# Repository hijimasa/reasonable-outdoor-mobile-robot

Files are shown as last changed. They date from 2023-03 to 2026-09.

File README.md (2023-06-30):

# 廉価版屋外向け移動ロボットプラットフォーム

# 注意事項
## 本プロジェクトのロボットに古いファームウェアであるM1502D_211のモーターを使用すると、速度フィードバックモードを有効にすると制御が発散するのか激しく振動する現象が確認されています。現在はオープンループモードを用いてArduino内でPID制御を入れることによって改善を図ってるので、ロボットに合わせて適宜パラメータチューニングが必要です。
   
# 概要
このリポジトリは、つくばチャレンジや中之島チャレンジで個人参加しやすい廉価な屋外向け移動ロボットプラットフォームを実現するために立ち上げたものです。
できるだけ廉価になるように設計してみたのですが、材料費は20万円程度となってしまったので、個人が手軽に始められるかどうかはちょっと怪しいです。
私個人が実験的に作成したものなので、質問やissueなどにはできる限り回答しますが、利活用は各々の自己責任のもとで行ってください。
本リポジトリが屋外向け移動ロボット開発の一助となれば幸いです。

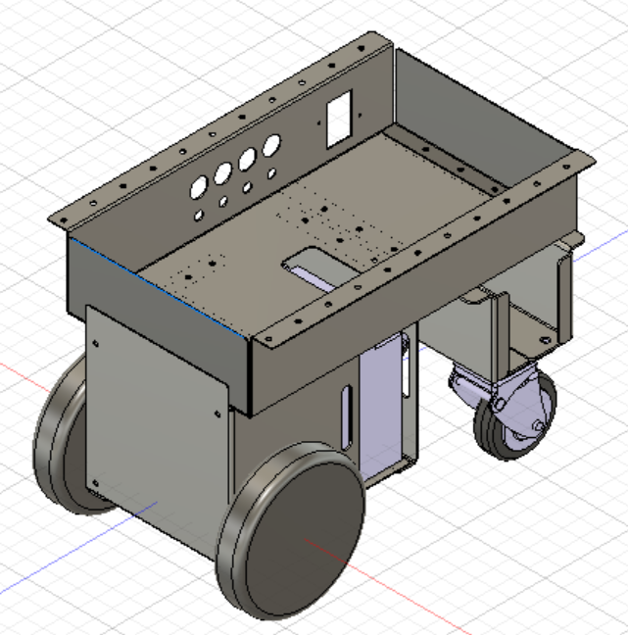
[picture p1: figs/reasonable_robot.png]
ロボット外観


# 特徴

- Direct Drive Tech社のタイヤ付きモータを採用

  タイヤの組付けなどの作業を省略した上で、部品数の低減に貢献しています。

- 24V20Ah相当のバッテリー搭載

  12V20Ahの鉛蓄電池を2つ直列に搭載しました。常時フル稼働でモータを駆動させるわけではないのであれば、屋外実験に十分な容量があると考えています。

- 自作のモータコントローラにより非常停止やブレーキ解除を実現

  今回採用したモータには非常停止やブレーキの解除機能がなく、作業性や安全面で問題があったので、制御PCとは独立したArduinoで機能を実現しました。
  何らかの規格に則っているわけではないので、安全性などについては今後の課題となっています。

# リポジトリの構成

- CAD

  様々な3DCADツールで利用しやすいSTEPファイルとROSでシミュレーションする際に利用できるSTLファイルを用意しています。
  
- schematics

  プラットフォームの回路図です。基本的にモータに電源とArduinoをつなげるだけです。

- BoM

  ロボット製作に必要となった部品表とかかった金額のメモです。参考までに。
  
- tools
  
  本リポジトリのロボットを活用するためのツールとして、モータのID変更やコントローラに関するArduinoプロジェクトなどを格納しています。
  
# 参照

- ROSパッケージ

  [reasonable_outdoor_mobile_robot_ros_controller](https://github.com/hijimasa/reasonable_outdoor_mobile_robot_ros_controller)
  
- ROS2パッケージ

  [reasonable_outdoor_mobile_robot_ros2_controller](https://github.com/hijimasa/reasonable_outdoor_mobile_robot_ros2_controller)

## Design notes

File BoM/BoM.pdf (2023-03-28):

## 廉価版屋外向け移動ロボットプラットフォーム 部品表

## 合計金額

品名 | 個数 | 参考単価 | 参考金額
DDT M1502D_211 タイヤ付きダイレクトドライブモーター | 2 | ￥41,536 | ￥83,072
Arduino Uno R3 | 1 | ￥3,960 | ￥3,960
SeeedStudio CAN-BUSシールド V2 | 1 | ￥4,070 | ￥4,070
LONG WP20-12 鉛蓄電池 | 2 | ￥7,590 | ￥15,180
シシク SAJ-100W キャスター | 2 | ￥6,990 | ￥13,980
パトライト TC60C06 端子台 | 2 | ￥1,490 | ￥2,980
パトライト JTJ602B ショートバー(10個セット) | 1 | ￥2,290 | ￥2,290
エーモン工業 2826 簡単接続分岐コネクター | 1 | ￥399 | ￥399
三菱電機 NF50-FA ブレーカー | 1 | ￥4,990 | ￥4,990
JAPPY IV 8sq 赤 JP ビニル絶縁電線(10m) | 1 | ￥2,290 | ￥2,290
JAPPY IV 8sq 黒 JP ビニル絶縁電線(10m) | 1 | ￥2,290 | ￥2,290
鍋屋バイテック SSHS-M6-6 ネジ（10本セット） | 3 | ￥1,390 | ￥4,170
モノタロウ MR8-6B(t=1.2) （100個セット） | 1 | ￥1,390 | ￥1,390
栃木屋 TM-MG-6 グロメット | 4 | ￥53 | ￥212
モノタロウ 73367954 防水トグルスイッチ | 1 | ￥1,890 | ￥1,890
ANDERSON POWER PRODUCTS 6331G3 バッテリコネクタ | 3 | ￥689 | ￥2,067
電菱 GC120A24 バッテリー充電器 | 1 | ￥11,900 | ￥11,900
【板金】MotorPlateBottom | 1 | ￥2,500 | ￥2,500
【板金】BatteryPlateBottom | 1 | ￥2,500 | ￥2,500
【板金】CasterPlate | 2 | ￥4,500 | ￥9,000
【板金】BatteryPlate | 2 | ￥4,500 | ￥9,000
【板金】MotorPlateLeft | 1 | ￥5,000 | ￥5,000
【板金】MotorPlateRight | 1 | ￥5,000 | ￥5,000
【板金】Futa | 1 | ￥3,000 | ￥3,000
【板金】BasePlate | 1 | ￥9,000 | ￥9,000
【板金】FrontPlate | 1 | ￥2,500 | ￥2,500
【板金】RearPlate | 1 | ￥2,500 | ￥2,500

￥207,130

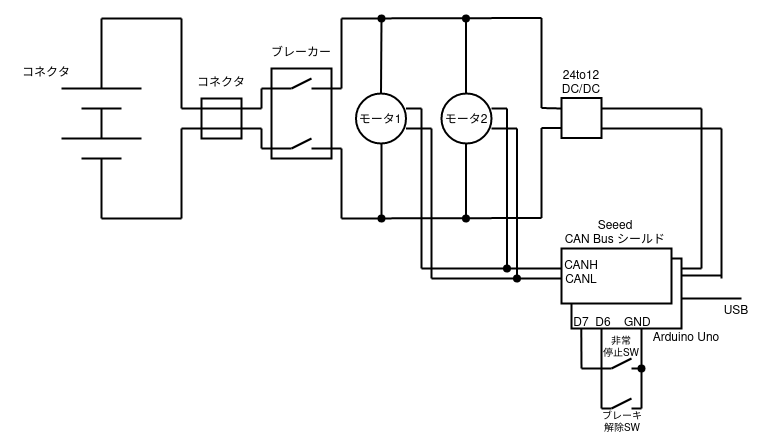
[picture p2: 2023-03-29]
schematics/schematics.png

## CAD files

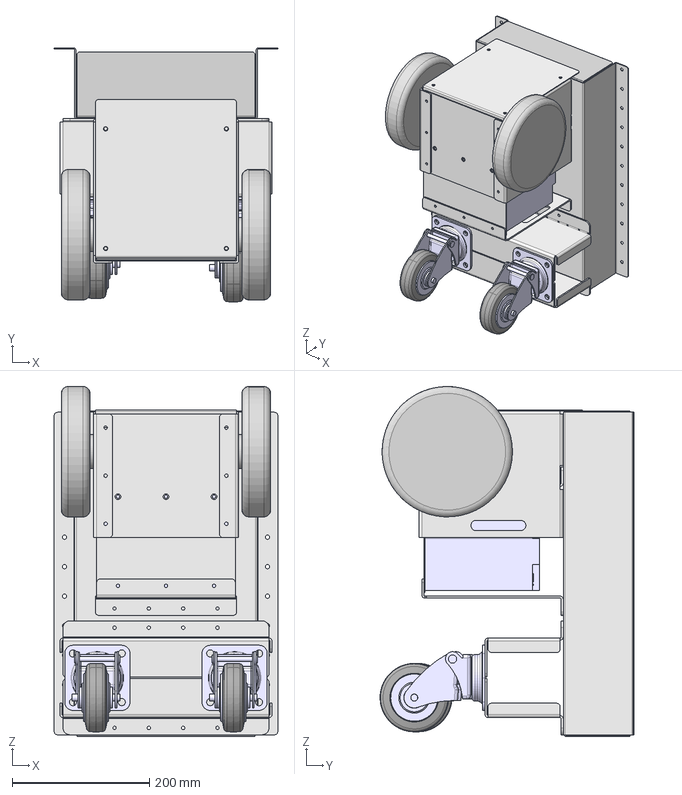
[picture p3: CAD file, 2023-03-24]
CAD/STEP/ReasonableOutdoorMobileRobot v14.step
326.0 x 369.9 x 510.0 mm
DDT_M1502D_211 x 2
SAJ-100W_TURN x 2
battery-22ah x 2
ReasonableOutdoorMoblieRobot-CasterPlate x 2
ReasonableOutdoorMoblieRobot-BatteryPlate x 2
ReasonableOutdoorMoblieRobot-BasePlate
ReasonableOutdoorMobileRobot-MotorPlateRight
ReasonableOutdoorRobot-Futa
SAJ-100W_TOP x 2
ReasonableOutdoorMobileRobot-BatteryPlateBottom
ReasonableOutdoorMobileRobot-MotorPlateBottom
ReasonableOutdoorMobileRobot-MotorPlateLeft
ReasonableOutdoorMobileRobot-RearPlate
ReasonableOutdoorMobileRobot-FrontPlate
SAJ-100W_TIRE x 2

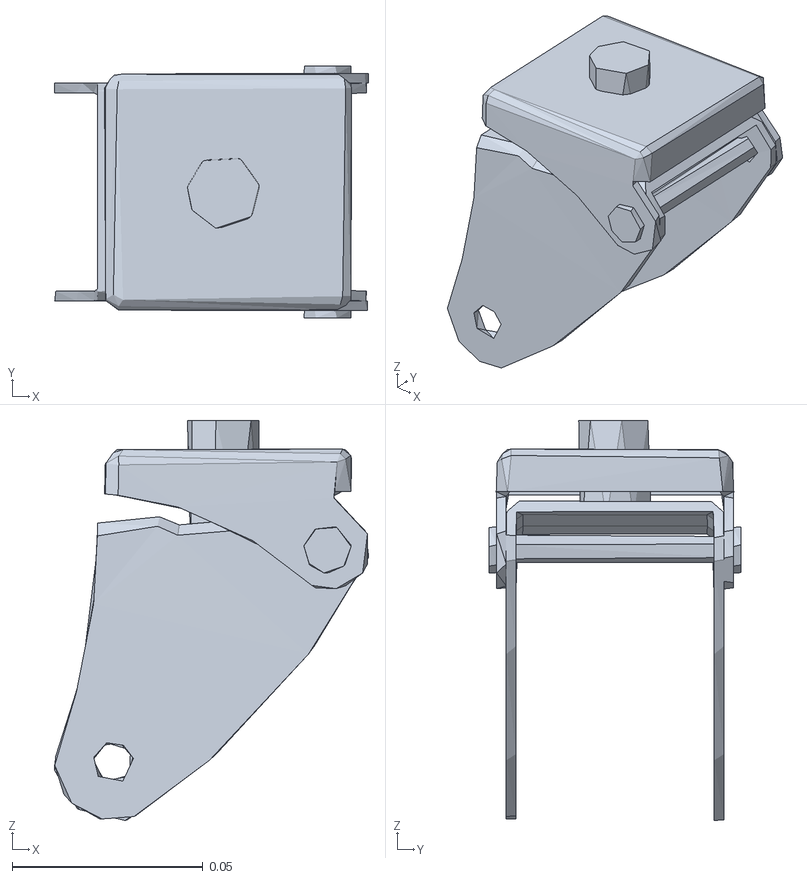
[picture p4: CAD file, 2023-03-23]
CAD/STL/SAJ-100W_TURN_light.stl
0.0823 x 0.066 x 0.105

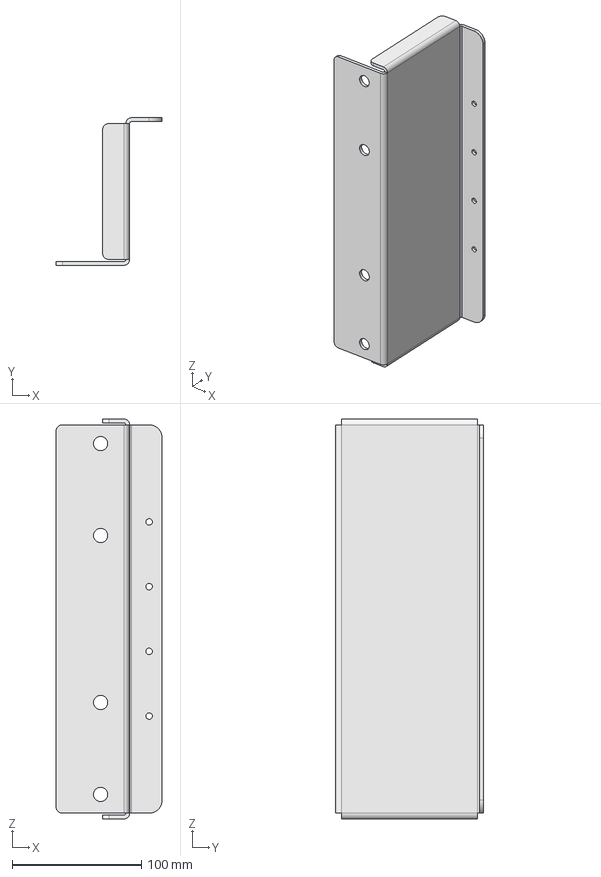
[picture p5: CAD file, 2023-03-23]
CAD/STEP/ReasonableOutdoorMoblieRobot-CasterPlate v20.step
82.0 x 114.0 x 309.0 mm

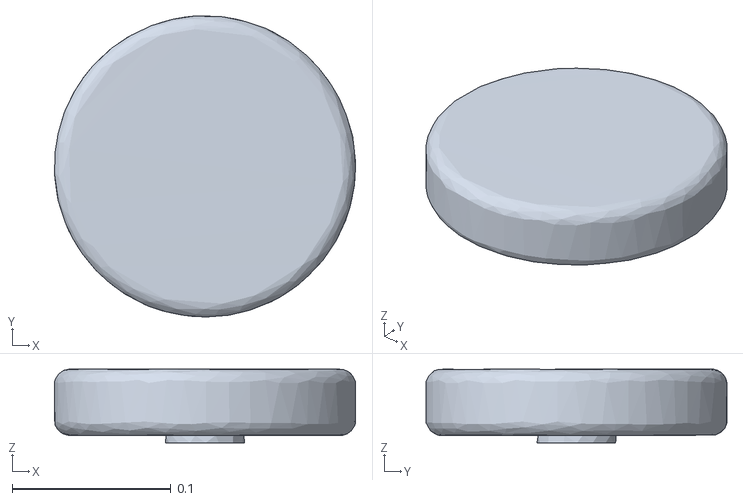
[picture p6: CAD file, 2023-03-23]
CAD/STL/DDT_M1502D_211_light.stl
0.19 x 0.19 x 0.0465

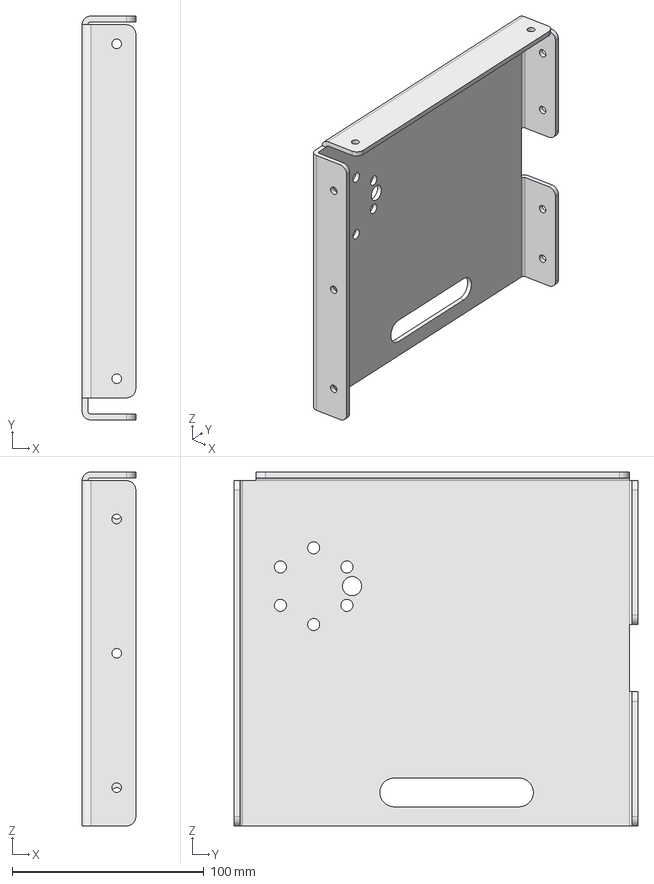
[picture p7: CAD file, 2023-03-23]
CAD/STEP/ReasonableOutdoorMobileRobot-MotorPlateRight v22.step
28.0 x 210.5 x 184.5 mm

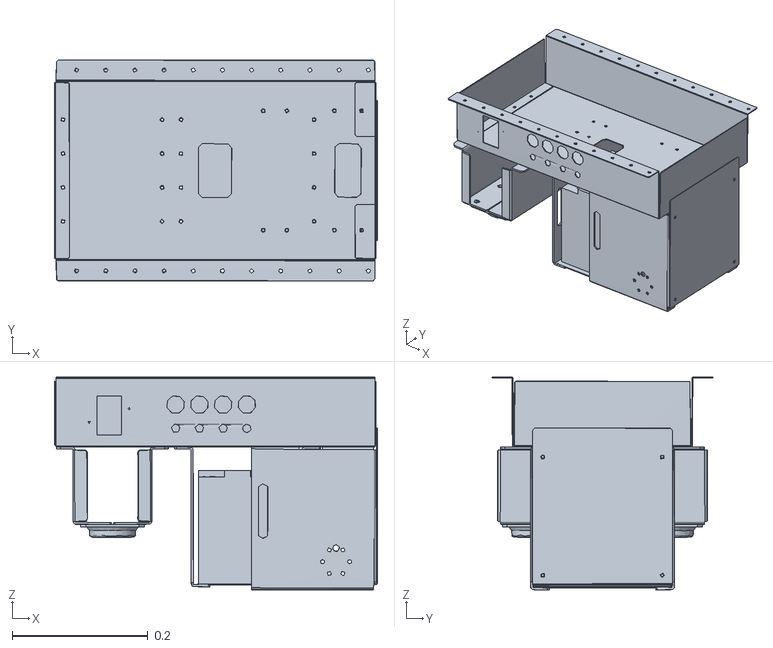
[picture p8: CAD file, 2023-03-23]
CAD/STL/ReasonableOutdoorMobileRobot-BaseUnit_light.stl
0.476 x 0.325 x 0.314

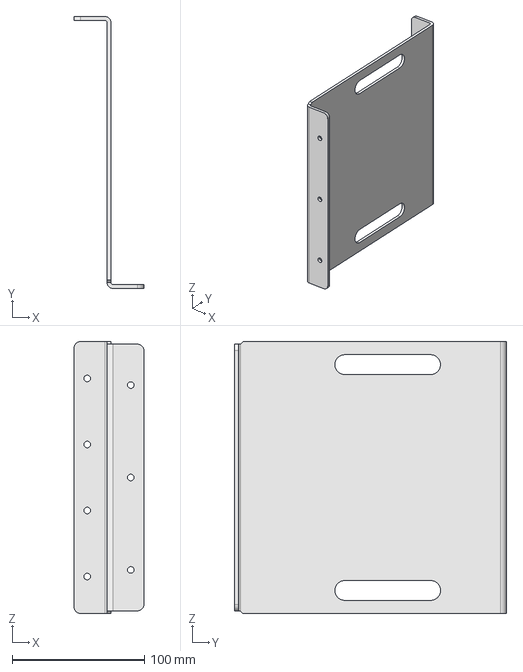
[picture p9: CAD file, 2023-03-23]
CAD/STEP/ReasonableOutdoorMoblieRobot-BatteryPlate v11.step
53.0 x 206.0 x 206.0 mm

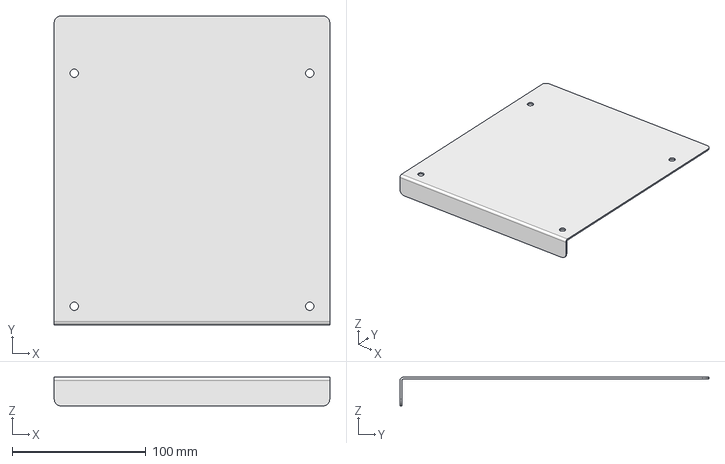
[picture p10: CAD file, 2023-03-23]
CAD/STEP/ReasonableOutdoorRobot-Futa v9.step
206.0 x 231.0 x 21.5 mm

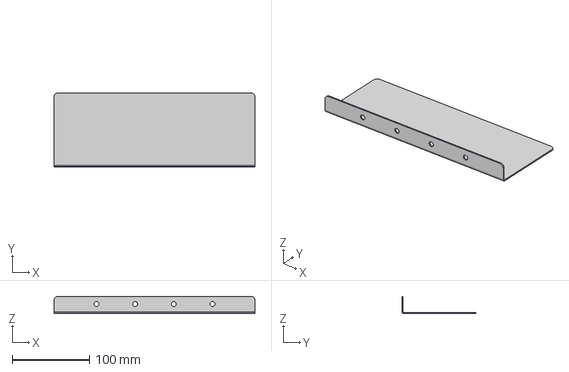
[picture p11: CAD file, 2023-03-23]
CAD/STEP/ReasonableOutdoorMobileRobot-RearPlate v4.step
260.0 x 96.0 x 22.5 mm

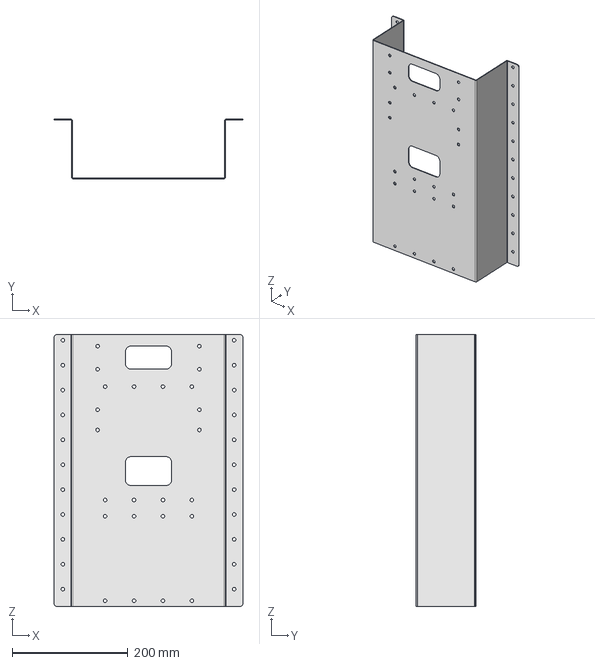
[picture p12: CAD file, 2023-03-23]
CAD/STEP/ReasonableOutdoorMoblieRobot-BasePlate v36.step
326.0 x 103.0 x 470.0 mm

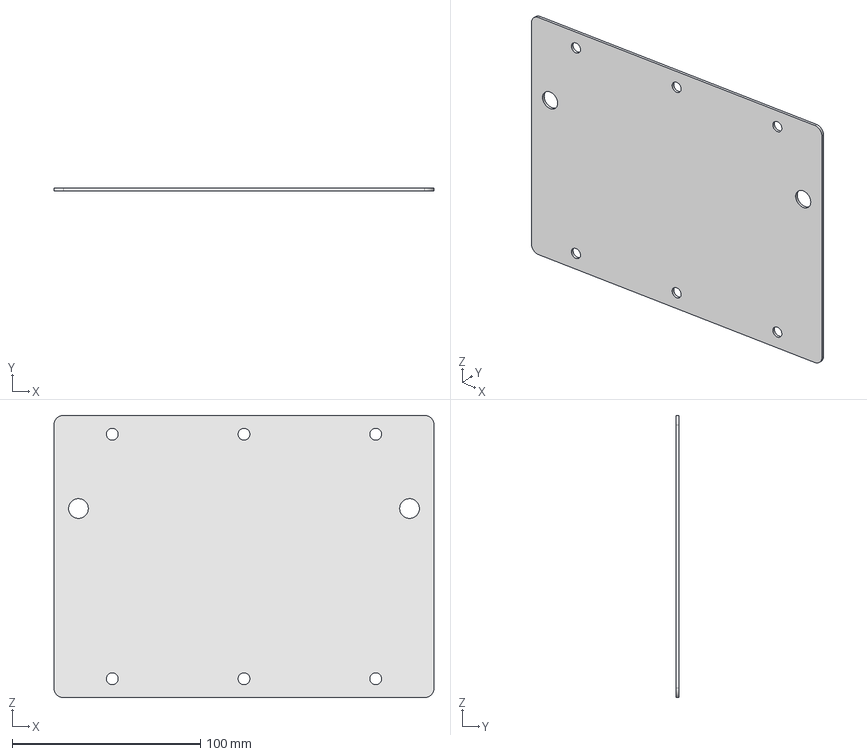
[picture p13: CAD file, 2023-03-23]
CAD/STEP/ReasonableOutdoorMobileRobot-BatteryPlateBottom v5.step
202.0 x 1.50 x 150.0 mm

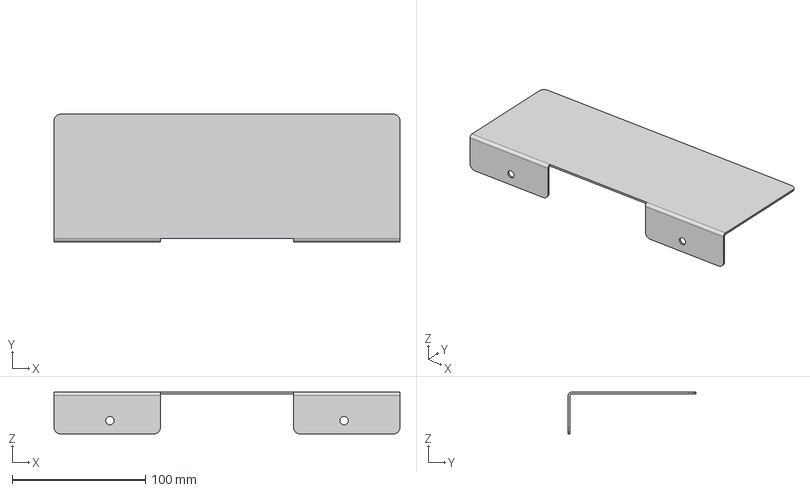
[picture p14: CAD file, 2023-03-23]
CAD/STEP/ReasonableOutdoorMobileRobot-FrontPlate v5.step
260.0 x 96.0 x 31.5 mm

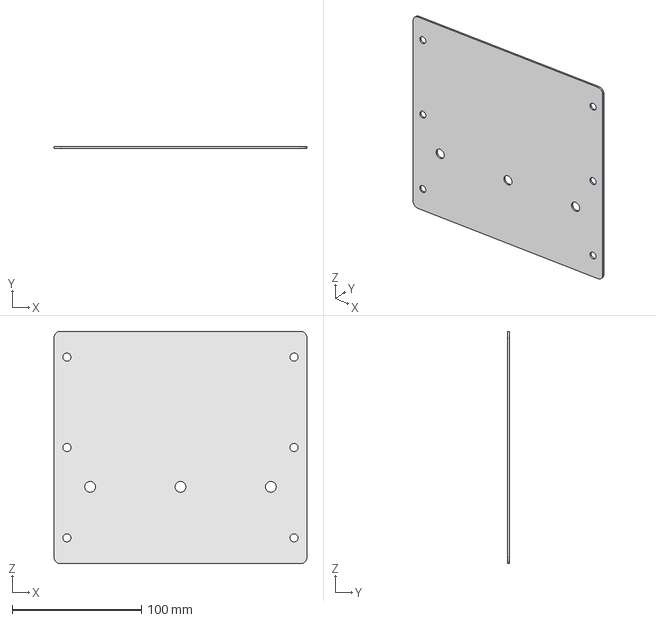
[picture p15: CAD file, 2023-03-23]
CAD/STEP/ReasonableOutdoorMobileRobot-MotorPlateBottom v3.step
196.0 x 1.50 x 180.0 mm

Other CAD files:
CAD/STEP/ReasonableOutdoorMobileRobot-MotorPlateLeft v4.step
CAD/STEP/CheepOutdoorMobileRobot v14.step

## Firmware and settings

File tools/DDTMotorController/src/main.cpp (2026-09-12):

#include <Arduino.h>
#include <SPI.h>
#include "mcp2515_can.h"

const int SPI_CS_PIN = 9;
mcp2515_can CAN(SPI_CS_PIN);

const int EMERGENCY_PIN = 7;
const int FREE_ROTATION_PIN = 6;

const int motor_total_num = 2;

// Which way a positive duty turns each motor, relative to the direction that
// motor reports as positive velocity. Measured on the bench with the wheels
// off the ground (tools/DDTMotorSignTest, 2026-09-12): ramping motor 0 to
// +4000 made it report -19 rpm with its angle falling, and -4000 made it
// report +20 rpm with the angle rising, while motor 1 reported +27 and -27 the
// obvious way round. So motor 0 is wired the other way about.
//
// The PID compares a target with that reported velocity, so without this the
// loop on motor 0 is positive feedback: a -1 rpm target drove the duty down,
// which drove the reported velocity up, which made the error more negative
// still, and the duty reached the rail inside four seconds. Commanded -1.3
// rpm, the wheel ran at +88 and the robot turned at 3.5 rad/s against a
// 0.1 rad/s request.
//
// This belongs on the duty and not on the feedback: the feedback is what the
// host integrates into odometry, and that was checked against a hand-turned
// wheel on 2026-09-06 and is right as it stands.
const int motor_duty_sign[8] = {-1, 1, 1, 1, 1, 1, 1, 1};
const int motor_decelation = 2000;
int motor_velocities[8]         = {0, 0, 0, 0, 0, 0, 0, 0};
int current_motor_velocities[8] = {0, 0, 0, 0, 0, 0, 0, 0};
int current_motor_currents[8]   = {0, 0, 0, 0, 0, 0, 0, 0};
int current_motor_angles[8]     = {0, 0, 0, 0, 0, 0, 0, 0};
int current_command[8]          = {0, 0, 0, 0, 0, 0, 0, 0};
int diff_vel[8][4]             = {{0}};
int diff_vel_index              = 0;
int k_p                         =  80;
int k_d                         =  10;
int k_i                         =  40;
bool is_drive_mode = false;

// Host link. One 6-byte frame per command: 0x55, two int16 rpm big-endian,
// checksum = sum of the first 5 bytes. The reply is 0x55, three int16 per
// motor (angle, rpm, current), checksum -- 14 bytes for two motors.
const int command_len = motor_total_num * 2 + 2;
byte command[command_len];
int command_len_received = 0;
// Stop the motors when the host goes quiet. Measured in time, not loop
// iterations, so it does not depend on how long a loop takes.
const unsigned long command_timeout_ms = 500;
unsigned long last_command_ms = 0;

// 500 kbaud, not 9600. A command is 6 bytes and a reply 14, which at 9600 is
// 20.8 ms on the wire every control cycle -- comparable to everything else the
// loop does. 500000 divides 16 MHz exactly (UBRR 3 with U2X, 0.00% error) and
// is a standard Linux baud constant, so both ends land on it without a
// mismatch; 115200 would be +2.12% on this AVR, inside 8N1 tolerance but with
// the least margin of the candidates and no benefit here. The host must be
// rebuilt with B500000 at the same time or the link goes silent.
const unsigned long HOST_BAUD = 500000;

// The PID below is an incremental form with no dt: k_i * error is added once
// per iteration, so the integral gain is proportional to the loop rate and the
// period is part of the tuning. It used to be three delay(10) calls -- two
// waiting for CAN status replies and one at the end -- so 30 ms whenever the
// motors answered promptly. Keeping the same 30 ms, held deliberately rather
// than falling out of where the sleeps landed, leaves the motor loop tuned as
// it was.
//
// It also has to stay paced: at 500 kbps a CAN frame is about 0.26 ms and this
// loop sends six of them, so running free would put the bus near saturation.
const unsigned long LOOP_PERIOD_MS = 30;

// The motors answer a status request in well under a millisecond. delay(10)
// spent ten of them doing nothing, twice a loop, and tied the loop period to
// where that tick happened to fall. checkReceive() is an SPI read, so this
// polls at SPI speed rather than spinning on nothing.
const unsigned long CAN_REPLY_TIMEOUT_US = 20000;

static bool waitForCanFrame(unsigned long timeout_us)
{
  const unsigned long start = micros();
  while (CAN_MSGAVAIL != CAN.checkReceive())
  {
    if (micros() - start > timeout_us)
    {
      return false;
    }
  }
  return true;
}

void setup() {
  unsigned char read_len;
  unsigned char read_buf[16];

  pinMode(EMERGENCY_PIN, INPUT_PULLUP);
  pinMode(FREE_ROTATION_PIN, INPUT_PULLUP);

  Serial.begin(HOST_BAUD);

  while (CAN_OK != CAN.begin(CAN_500KBPS)) {             // init can bus : baudrate = 500k
    delay(100);
  }

  unsigned char registor_stmp[8] = {0x00, 0x00, 0, 0, 0, 0, 0, 0};
  CAN.sendMsgBuf(0x109, 0, 8, registor_stmp);
  delay(10);

  unsigned char feedback_stmp[8] = {0x80, 0x80, 0, 0, 0, 0, 0, 0};
  CAN.sendMsgBuf(0x106, 0, 8, feedback_stmp);
  delay(10);

  // flush can data
  while (1)
  {
    int timeout_count = 0;
    while (CAN_MSGAVAIL != CAN.checkReceive())
    {
      delay(10);
      timeout_count++;
      if (timeout_count > 100)
      {
        break;
      }
    }
    if (timeout_count > 100)
    {
      break;
    }

    CAN.readMsgBuf(&read_len, read_buf);
  }
}

// Answer whatever the host has sent. Called from loop() and again while the
// loop waits out its period, so a command is replied to within microseconds
// of arriving instead of whenever the loop next comes round to it. The reply
// used to be assembled once a pass, behind the CAN status polling, so its
// latency was anywhere from nothing to a full loop depending on when the
// command landed -- and that spread is what the host saw as an uneven cycle.
static void serviceHostLink(int emergency_pin_mode)
{
  // Host link. Scan for the 0x55 header instead of trusting that whatever
  // is in the buffer starts a frame: a byte lost to an overrun used to leave
  // every following command misaligned until the buffer happened to empty.
  // Every valid frame gets a status reply, so the host sees one answer per
  // command it sent.
  while (Serial.available() > 0)
  {
    byte b = Serial.read();
    if (command_len_received == 0 && b != 85)
    {
      continue;
    }
    command[command_len_received++] = b;
    if (command_len_received < command_len)
    {
      continue;
    }
    command_len_received = 0;

    byte check_byte = 0;
    for (int i = 0; i < command_len - 1; i++)
    {
      check_byte += command[i];
    }
    if (check_byte != command[command_len - 1])
    {
      continue;
    }

    last_command_ms = millis();
    if (emergency_pin_mode == LOW) // not emergency
    {
      for (int motor_num = 0; motor_num < motor_total_num; motor_num++)
      {
        motor_velocities[motor_num] = (command[2*motor_num+1] << 8) + command[2*motor_num+2];
      }
    }

    byte reply_check = 85;
    Serial.write((byte)85);
    for (int motor_num = 0; motor_num < motor_total_num; motor_num++)
    {
      Serial.write(highByte(current_motor_angles[motor_num]));
      Serial.write(lowByte(current_motor_angles[motor_num]));
      reply_check += highByte(current_motor_angles[motor_num]);
      reply_check += lowByte(current_motor_angles[motor_num]);
      Serial.write(highByte(current_motor_velocities[motor_num]));
      Serial.write(lowByte(current_motor_velocities[motor_num]));
      reply_check += highByte(current_motor_velocities[motor_num]);
      reply_check += lowByte(current_motor_velocities[motor_num]);
      Serial.write(highByte(current_motor_currents[motor_num]));
      Serial.write(lowByte(current_motor_currents[motor_num]));
      reply_check += highByte(current_motor_currents[motor_num]);
      reply_check += lowByte(current_motor_currents[motor_num]);
    }
    Serial.write(reply_check);
  }
}

void loop() {
  const unsigned long loop_start_ms = millis();
  unsigned char read_len;
  unsigned char read_buf[16];

  int free_rotation_pin_mode = digitalRead(FREE_ROTATION_PIN);
  int emergency_pin_mode = digitalRead(EMERGENCY_PIN);

  if (free_rotation_pin_mode == LOW) // free
  {
    const unsigned char disable_mode_stmp[8] = {0x09, 0x09, 0, 0, 0, 0, 0, 0};
    CAN.sendMsgBuf(0x105, 0, 8, disable_mode_stmp);
    for (int motor_num = 0; motor_num < motor_total_num; motor_num++)
    {
      if (waitForCanFrame(CAN_REPLY_TIMEOUT_US))
      {
        CAN.readMsgBuf(&read_len, read_buf);
      }
    }

    is_drive_mode = false;
  }
  else // normal
  {
    if (is_drive_mode == false)
    {
      is_drive_mode = true;
      const unsigned char open_loop_mode_stmp[8] = {0x00, 0x00, 0, 0, 0, 0, 0, 0};
      CAN.sendMsgBuf(0x105, 0, 8, open_loop_mode_stmp);
      for (int motor_num = 0; motor_num < motor_total_num; motor_num++)
      {
        if (waitForCanFrame(CAN_REPLY_TIMEOUT_US))
        {
          CAN.readMsgBuf(&read_len, read_buf);
        }
      }
      delay(10);
    }

    unsigned char velocities_stmp[8] = {0, 0, 0, 0, 0, 0, 0, 0};
    if (emergency_pin_mode == LOW) // not emergency
    {
      for (int motor_num = 0; motor_num < 4; motor_num++)
      {
        int old_diff_index = diff_vel_index - 1;
        if (old_diff_index < 0)
        {
          old_diff_index += 4;
        }
        int old_diff_index2 = diff_vel_index - 2;
        if (old_diff_index2 < 0)
        {
          old_diff_index2 += 4;
        }
        int diff_control_amount = k_p * (diff_vel[motor_num][diff_vel_index] - diff_vel[motor_num][old_diff_index])
                                 + k_d * ((diff_vel[motor_num][diff_vel_index] - diff_vel[motor_num][old_diff_index]) - (diff_vel[motor_num][old_diff_index] - diff_vel[motor_num][old_diff_index2]))
                                 + k_i * diff_vel[motor_num][diff_vel_index];
        if ((long) diff_control_amount + (long) current_command[motor_num] > 32767)
        {
          current_command[motor_num] = 32767;
        }
        else if ((long) diff_control_amount + (long) current_command[motor_num] < -32767)
        {
          current_command[motor_num] = -32767;
        }
        else
        {
          current_command[motor_num] += diff_control_amount;
        }
        const int duty = motor_duty_sign[motor_num] * current_command[motor_num];
        velocities_stmp[motor_num*2] = highByte(duty);
        velocities_stmp[motor_num*2+1] = lowByte(duty);
      }
    }
    else
    {
      for (int motor_num = 0; motor_num < 4; motor_num++)
      {
        if (current_command[motor_num] > 0)
        {
          current_command[motor_num] -= motor_decelation;
          if (current_command[motor_num] < 0)
          {
            current_command[motor_num] = 0;
          }
        }
        if (current_command[motor_num] < 0)
        {
          current_command[motor_num] += motor_decelation;
          if (current_command[motor_num] > 0)
          {
            current_command[motor_num] = 0;
          }
        }
        const int duty = motor_duty_sign[motor_num] * current_command[motor_num];
        velocities_stmp[motor_num*2] = highByte(duty);
        velocities_stmp[motor_num*2+1] = lowByte(duty);
      }
    }
    CAN.sendMsgBuf(0x32, 0, 8, velocities_stmp);
    if (emergency_pin_mode == LOW) // not emergency
    {
      for (int motor_num = 4; motor_num < 8; motor_num++)
      {
        int old_diff_index = diff_vel_index - 1;
        if (old_diff_index < 0)
        {
          old_diff_index += 4;
        }
        int old_diff_index2 = diff_vel_index - 2;
        if (old_diff_index2 < 0)
        {
          old_diff_index2 += 4;
        }
        int diff_control_amount = k_p * (diff_vel[motor_num][diff_vel_index] - diff_vel[motor_num][old_diff_index])
                                 + k_d * ((diff_vel[motor_num][diff_vel_index] - diff_vel[motor_num][old_diff_index]) - (diff_vel[motor_num][old_diff_index] - diff_vel[motor_num][old_diff_index2]))
                                 + k_i * diff_vel[motor_num][diff_vel_index];
        if ((long) diff_control_amount + (long) current_command[motor_num] > 32767)
        {
          current_command[motor_num] = 32767;
        }
        else if ((long) diff_control_amount + (long) current_command[motor_num] < -32767)
        {
          current_command[motor_num] = -32767;
        }
        else
        {
          current_command[motor_num] += diff_control_amount;
        }
        const int duty = motor_duty_sign[motor_num] * current_command[motor_num];
        velocities_stmp[(motor_num-4)*2] = highByte(duty);
        velocities_stmp[(motor_num-4)*2+1] = lowByte(duty);
      }
    }
    else
    {
      for (int motor_num = 4; motor_num < 8; motor_num++)
      {
        if (current_command[motor_num] > 0)
        {
          current_command[motor_num] -= motor_decelation;
          if (current_command[motor_num] < 0)
          {
            current_command[motor_num] = 0;
          }
        }
        if (current_command[motor_num] < 0)
        {
          current_command[motor_num] += motor_decelation;
          if (current_command[motor_num] > 0)
          {
            current_command[motor_num] = 0;
          }
        }
        const int duty = motor_duty_sign[motor_num] * current_command[motor_num];
        velocities_stmp[(motor_num-4)*2] = highByte(duty);
        velocities_stmp[(motor_num-4)*2+1] = lowByte(duty);
      }
    }
    CAN.sendMsgBuf(0x33, 0, 8, velocities_stmp);
  }

  serviceHostLink(emergency_pin_mode);

  if (millis() - last_command_ms > command_timeout_ms)
  {
    for (int motor_num = 0; motor_num < motor_total_num; motor_num++)
    {
      motor_velocities[motor_num] = 0;
    }
  }

  // One step per loop, not one per motor. diff_vel_index is a single index into
  // a per-motor ring, and advancing it inside the loop below gave motor 0 the
  // odd slots and motor 1 the even ones. The PID reads diff_vel[motor][cur],
  // [cur-1], [cur-2] from whatever the index happened to be, so motor 0 was
  // differentiating slots it had never written -- its error history read as
  // 0, E, 0 and the increment came out as -(k_p + 2*k_d) * E, the wrong sign,
  // which walks the duty to the rail instead of tracking. Motor 1 read
  // e[n-1] as a permanent zero, so its k_d term was extra proportional gain
  // rather than damping. Advancing once here gives every motor the same slot
  // and makes each ring its own history.
  diff_vel_index++;
  if (diff_vel_index >= 4)
  {
    diff_vel_index = 0;
  }

  unsigned char get_status_stmp[8] = {0x00, 0x01, 0x02, 0x04, 0xAA, 0, 0, 0};
  for (int motor_num = 0; motor_num < motor_total_num; motor_num++)
  {
    get_status_stmp[0] = motor_num + 1;
    CAN.sendMsgBuf(0x107, 0, 8, get_status_stmp);
    // A motor that does not answer keeps its last reading rather than whatever
    // is left in read_buf. There was no timeout here at all, so a silent motor
    // would have stopped the loop for good.
    if (waitForCanFrame(CAN_REPLY_TIMEOUT_US))
    {
      CAN.readMsgBuf(&read_len, read_buf);
      current_motor_velocities[motor_num] = (read_buf[0] << 8) + read_buf[1];
      current_motor_currents[motor_num] = (read_buf[2] << 8) + read_buf[3];
      current_motor_angles[motor_num] = (read_buf[4] << 8) + read_buf[5];
    }
    
    if (emergency_pin_mode == LOW && free_rotation_pin_mode == HIGH) // not emergency
    {
      diff_vel[motor_num][diff_vel_index] = motor_velocities[motor_num] - current_motor_velocities[motor_num];
    }
    else // command becomes zero if emergency is enable.
    {
      diff_vel[motor_num][diff_vel_index] = 0;
    }
  }

  // Hold the period rather than sleeping a flat 10 ms on top of however long
  // the work took, and spend the wait answering the host instead of idling.
  while (millis() - loop_start_ms < LOOP_PERIOD_MS)
  {
    serviceHostLink(emergency_pin_mode);
  }
}

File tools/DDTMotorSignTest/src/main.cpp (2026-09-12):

/**
 * Which way does a positive duty turn the wheel, and which sign comes back?
 *
 * WHEELS OFF THE GROUND. This drives each motor open loop, one at a time, and
 * prints the status the motor returns, so the two mappings the controller
 * assumes can be read off instead of inferred:
 *
 *   duty sign  -> which way the wheel physically turns
 *   turn       -> the sign of the velocity and angle the motor reports
 *
 * The controller's PID needs those two to agree. If they do not, the error
 * grows instead of shrinking and the duty walks to the rail: commanded -1 rpm,
 * measured +88, which is what this robot does today.
 *
 * It runs one pass and then holds every motor at zero. Output is CSV at
 * 500000 baud, the same rate the real firmware uses:
 *
 *   ms,phase,motor,duty,vel0,vel1,cur0,cur1,ang0,ang1
 *
 * The emergency and free-rotation inputs are honoured: emergency forces duty
 * to zero, free rotation puts the motors in their disabled mode, same sense as
 * the real firmware.
 */
#include <Arduino.h>
#include <SPI.h>
#include "mcp2515_can.h"

const int SPI_CS_PIN = 9;
mcp2515_can CAN(SPI_CS_PIN);

const int EMERGENCY_PIN = 7;
const int FREE_ROTATION_PIN = 6;

const int motor_total_num = 2;
const unsigned long HOST_BAUD = 500000;
const unsigned long CAN_REPLY_TIMEOUT_US = 20000;

// Ramp to this rather than stepping: if the wheel does not break away at a low
// duty the ramp shows where it does, and a step into a stiff drivetrain tells
// you nothing about the threshold.
const int TEST_DUTY = 4000;          // of 32767
const unsigned long RAMP_MS = 2500;
const unsigned long HOLD_MS = 1000;
const unsigned long REST_MS = 1500;

int reported_vel[4] = {0, 0, 0, 0};
int reported_cur[4] = {0, 0, 0, 0};
int reported_ang[4] = {0, 0, 0, 0};

static bool waitForCanFrame(unsigned long timeout_us)
{
  const unsigned long start = micros();
  while (CAN_MSGAVAIL != CAN.checkReceive())
  {
    if (micros() - start > timeout_us)
    {
      return false;
    }
  }
  return true;
}

static void sendDuty(int duty0, int duty1)
{
  unsigned char payload[8] = {0, 0, 0, 0, 0, 0, 0, 0};
  payload[0] = highByte(duty0);
  payload[1] = lowByte(duty0);
  payload[2] = highByte(duty1);
  payload[3] = lowByte(duty1);
  CAN.sendMsgBuf(0x32, 0, 8, payload);
}

static void readStatus()
{
  unsigned char read_len;
  unsigned char read_buf[16];
  unsigned char request[8] = {0x00, 0x01, 0x02, 0x04, 0xAA, 0, 0, 0};
  for (int motor_num = 0; motor_num < motor_total_num; motor_num++)
  {
    request[0] = motor_num + 1;
    CAN.sendMsgBuf(0x107, 0, 8, request);
    if (waitForCanFrame(CAN_REPLY_TIMEOUT_US))
    {
      CAN.readMsgBuf(&read_len, read_buf);
      // Signed on purpose. The reply carries int16 two's complement; reading it
      // unsigned is one of the things this sketch exists to rule out.
      reported_vel[motor_num] = (int)((read_buf[0] << 8) | read_buf[1]);
      reported_cur[motor_num] = (int)((read_buf[2] << 8) | read_buf[3]);
      reported_ang[motor_num] = (int)((read_buf[4] << 8) | read_buf[5]);
    }
  }
}

void setup()
{
  pinMode(EMERGENCY_PIN, INPUT_PULLUP);
  pinMode(FREE_ROTATION_PIN, INPUT_PULLUP);
  Serial.begin(HOST_BAUD);

  while (CAN_OK != CAN.begin(CAN_500KBPS))
  {
    delay(100);
  }

  unsigned char registor_stmp[8] = {0x00, 0x00, 0, 0, 0, 0, 0, 0};
  CAN.sendMsgBuf(0x109, 0, 8, registor_stmp);
  delay(10);
  unsigned char feedback_stmp[8] = {0x80, 0x80, 0, 0, 0, 0, 0, 0};
  CAN.sendMsgBuf(0x106, 0, 8, feedback_stmp);
  delay(10);

  // Drain whatever the motors queued while all that went out.
  while (waitForCanFrame(50000))
  {
    unsigned char read_len;
    unsigned char read_buf[16];
    CAN.readMsgBuf(&read_len, read_buf);
  }

  const unsigned char open_loop_mode[8] = {0x00, 0x00, 0, 0, 0, 0, 0, 0};
  CAN.sendMsgBuf(0x105, 0, 8, open_loop_mode);
  delay(10);
  while (waitForCanFrame(50000))
  {
    unsigned char read_len;
    unsigned char read_buf[16];
    CAN.readMsgBuf(&read_len, read_buf);
  }

  Serial.println();
  Serial.println(F("ms,phase,motor,duty,vel0,vel1,cur0,cur1,ang0,ang1"));
}

// Four passes: motor 0 forward, motor 0 reverse, motor 1 forward, motor 1
// reverse. The other motor is held at zero throughout, so nothing has to be
// untangled afterwards.
struct Pass { int motor; int sign; const char *name; };
const Pass passes[] = {
  {0, +1, "m0+"}, {0, -1, "m0-"}, {1, +1, "m1+"}, {1, -1, "m1-"},
};
const int pass_count = sizeof(passes) / sizeof(passes[0]);

int pass_index = 0;
unsigned long phase_start = 0;
bool finished = false;

void loop()
{
  const int free_rotation = digitalRead(FREE_ROTATION_PIN);
  const int emergency = digitalRead(EMERGENCY_PIN);

  if (free_rotation == LOW)                       // free rotation requested
  {
    const unsigned char disable_mode[8] = {0x09, 0x09, 0, 0, 0, 0, 0, 0};
    CAN.sendMsgBuf(0x105, 0, 8, disable_mode);
    readStatus();
    Serial.print(millis()); Serial.println(F(",free,-,0,,,,,,"));
    delay(100);
    phase_start = millis();                       // do not count this against a pass
    return;
  }

  if (phase_start == 0)
  {
    phase_start = millis();
  }
  const unsigned long t = millis() - phase_start;
  const unsigned long pass_len = RAMP_MS + HOLD_MS + REST_MS;

  int duty = 0;
  const char *phase = "rest";
  if (!finished)
  {
    if (t < RAMP_MS)
    {
      duty = (int)((long)TEST_DUTY * t / RAMP_MS);
      phase = "ramp";
    }
    else if (t < RAMP_MS + HOLD_MS)
    {
      duty = TEST_DUTY;
      phase = "hold";
    }
    duty *= passes[pass_index].sign;
  }
  else
  {
    phase = "done";
  }

  if (emergency != LOW)                           // emergency engaged
  {
    duty = 0;
    phase = "estop";
  }

  const int motor = finished ? -1 : passes[pass_index].motor;
  sendDuty(motor == 0 ? duty : 0, motor == 1 ? duty : 0);
  readStatus();

  Serial.print(millis()); Serial.print(',');
  Serial.print(phase); Serial.print(',');
  Serial.print(motor); Serial.print(',');
  Serial.print(duty); Serial.print(',');
  Serial.print(reported_vel[0]); Serial.print(',');
  Serial.print(reported_vel[1]); Serial.print(',');
  Serial.print(reported_cur[0]); Serial.print(',');
  Serial.print(reported_cur[1]); Serial.print(',');
  Serial.print(reported_ang[0]); Serial.print(',');
  Serial.println(reported_ang[1]);

  if (!finished && t >= pass_len)
  {
    phase_start = millis();
    pass_index++;
    if (pass_index >= pass_count)
    {
      finished = true;
      pass_index = pass_count - 1;
    }
  }
  delay(100);
}

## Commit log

2023-03-23 add BoM
    [BoM.ods]
2023-03-23 add CAD
    [CheepOutdoorMobileRobot v14.step, CheepOutdoorMobileRobot-BaseUnit_light.stl, CheepOutdoorMobileRobot-BatteryPlateBottom v5.step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]
2023-03-24 update BoM
2023-03-24 rename all
    [BoM.ods, ReasonableOutdoorMobileRobot v14.step, ReasonableOutdoorMobileRobot-BaseUnit_light.stl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]
2023-03-26 add MotorIDConfigure
2023-03-29 add schematics
2023-06-30 add pid control code
2023-06-30 upgrade pid control
2026-09-06 Stop flooding the host link with debug prints, and frame the commands properly
    The motor controller printed four lines per motor per loop over the same
    9600 baud link that carries the commands. That alone held the loop at
    ~13 Hz, and on the robot it went further: the host's input buffer filled,
    the USB bridge stalled, and a single 6-byte command could take 80 s to be
    accepted -- the robot moved a minute after the key was pressed.
    Commands are now parsed by scanning for the 0x55 header and checking the
    sum, one status reply per valid frame, instead of taking whatever bytes
    were in the buffer as a frame. The command timeout is 500 ms of wall time
    rather than 100 loop iterations. Two index bug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
    [main.cpp]
2026-09-07 Answer the host when it asks, and stop sleeping through the CAN replies
    The robot stutters under Nav2 and not under teleop, and the host side turned out
    to be waiting on this board. Three delay(10) calls set the loop period: two
    waiting for CAN status replies and one at the end. The motors answer a status
    request in well under a millisecond, so both of those waits were ten
    milliseconds of nothing, and the period came out at 30 ms whenever the motors
    were prompt.
    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
2026-09-07 Give each motor its own PID history
    diff_vel_index is a single index into a per-motor ring, and it was advanced
    once per motor inside the status loop rather than once per loop. With two
    motors it therefore moved by two every pass, so motor 0 only ever wrote the odd
    slots and motor 1 only the even ones, while the PID above read
    diff_vel[motor][cur], [cur-1] and [cur-2] from whatever the index had reached.
    Run against a model of the two motors with both commanded to +50 rpm, the real
    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
2026-09-12 Drive motor 0 the way it reports, and keep the bench sketch that showed which way that is
    Motor 0 is wired the other way about from motor 1: on the bench with the
    wheels off the ground, ramping its duty to +4000 made it report -19 rpm
    with its angle falling, and -4000 made it report +20 with the angle
    rising. Motor 1 reported +27 and -27 the obvious way round.
    The PID compares a target against that reported velocity, so on motor 0
    the loop was positive feedback. A -1 rpm target drove the duty down, which
    drove the reported velocity up, which made the error more negative still.
    The duty reached the rail in four seconds: commanded -1.3 rpm, the wheel
    ran at +88, and the robot turned at 3.5 ra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
    [main.cpp]
